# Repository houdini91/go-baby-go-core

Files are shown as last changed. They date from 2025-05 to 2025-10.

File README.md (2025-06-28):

# GoBabyGo Core Build Kit

This repository contains the core set of open-source 3D-printed components developed for **GoBabyGo** — a volunteer-driven nonprofit dedicated to building adapted electric cars for children with disabilities.

🖨️ Printable model pages:
🔗 [Core Build Kit Models](https://www.printables.com/model/875079-adaptive-electric-car-core-kit-gobabygo-israel)
🔗 [Stabilized Adaptive Push Button Models](https://www.printables.com/model/993443-stabilized-adaptive-switch-go-baby-go-il/files)

📘 Learn more in our blog post:
🔗 [Core Build Kit Overview](https://medium.com/@mikeystrauss/adapting-cars-for-children-with-disabilities-the-gobabygo-core-build-kit-08175c2a7b7c)

Maintainers:
* Mikey Strauss - GoBabyGo Israel - `mdstrauss91@gmail.com`
* Christopher Auger-Dominguez - Center for Initiatives in Jewish Education  
* Barbara Sehgal - Center for Initiatives in Jewish Education  

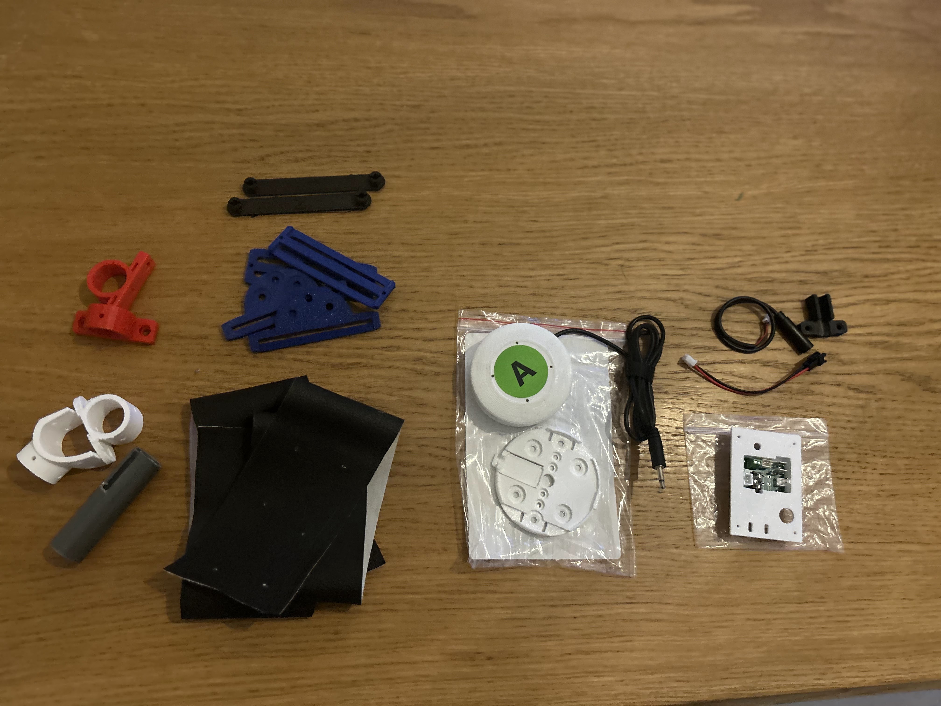
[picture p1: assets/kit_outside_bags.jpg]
Kit View

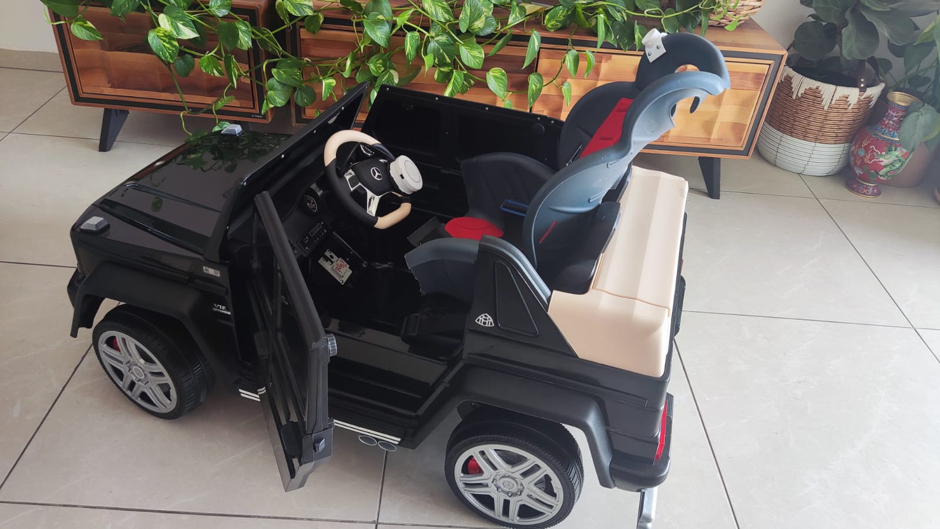
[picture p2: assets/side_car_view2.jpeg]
Car View


### Empowering Mobility Through Open, Accessible Design

At **GoBabyGo**, we believe every child deserves the freedom to move, explore, and experience independence. The **Core Build Kit** is our open-source effort to share the core components and lessons from years of building customized electric cars for children with disabilities.

This kit reflects over a decade of iterative learning, hands-on problem-solving, and feedback from hundreds of families and builders. Our mission is to make adaptive ride-on vehicles simpler, more consistent, and easier for other GoBabyGo chapters, makers, and caregivers to replicate and customize.

> 💡 The kit is built for collaboration. Whether you're improving it for your local chapter or adapting it to new use cases, we welcome your ideas and contributions.

---

### What's Inside the Kit?

#### 🔘 **Push Button Adaptation**

We replace foot pedals with accessible hand- or head-activated push buttons. The kit includes:

* A no-solder generic **pedal-to-jack adapter**
* Modular **push button mounts** for off-the-shelf (e.g., Logitech Adaptive Kit) and custom buttons
* Stable, flexible **mounting connectors** for various control schemes
* Mods and Extentions models for different use cases.

<!-- ![Pedal Jack Adaptor](assets/pedal_jack_adaptor.jpeg)
![Assembly Top](assets/pedal_jack_assembled_top.jpeg)
![Assembly buttom](assets/pedal_jack_assembled_buttom.jpeg)
![Pedal Jack Adaptor 3D](assets/pedal_jack_pcb_front_v1.png)
 -->

|  |  |
| --- | --- |
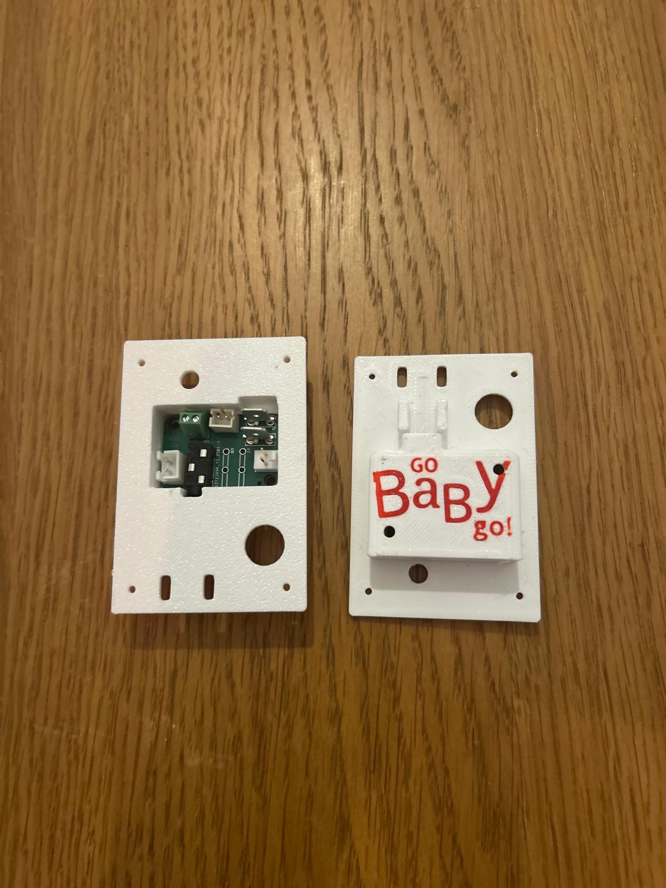
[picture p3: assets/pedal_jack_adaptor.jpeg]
Pedal Jack Adaptor
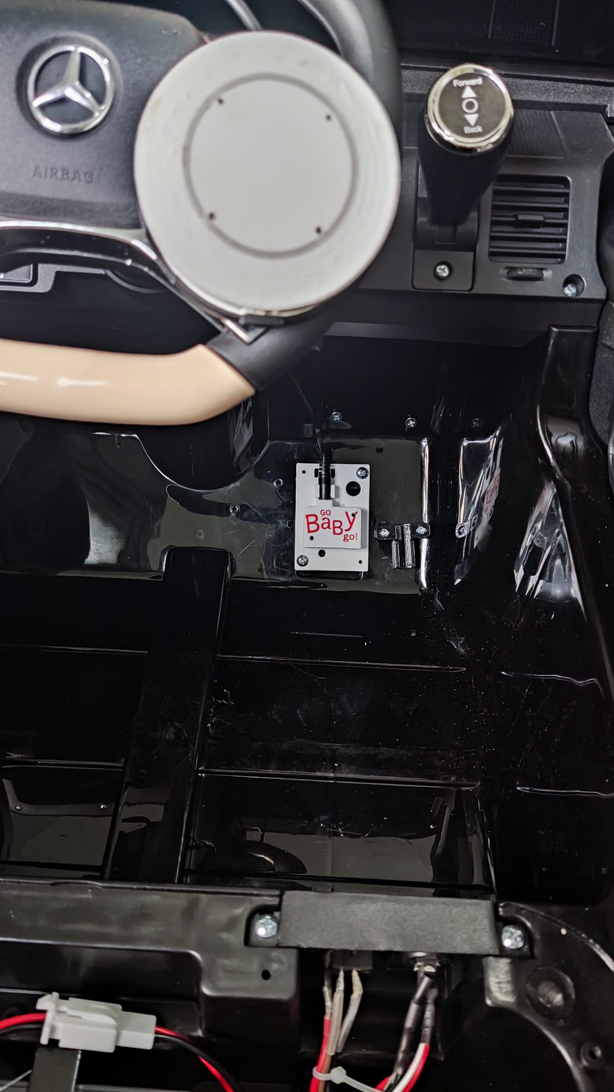
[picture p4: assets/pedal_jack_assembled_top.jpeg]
Assembly Top
| |  |
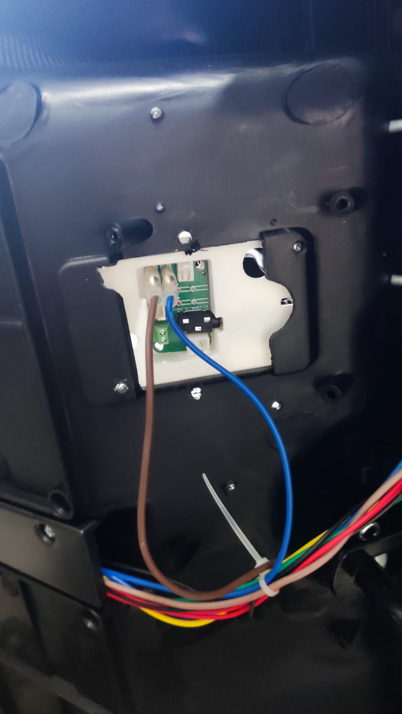
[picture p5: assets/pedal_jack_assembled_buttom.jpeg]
Assembly buttom
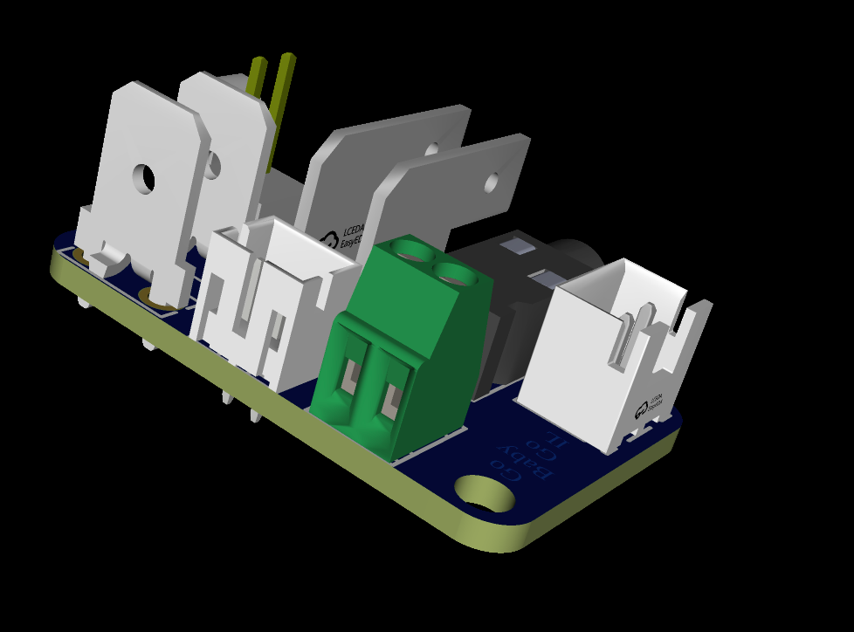
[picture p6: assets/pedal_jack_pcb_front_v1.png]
Pedal Jack Adaptor 3D
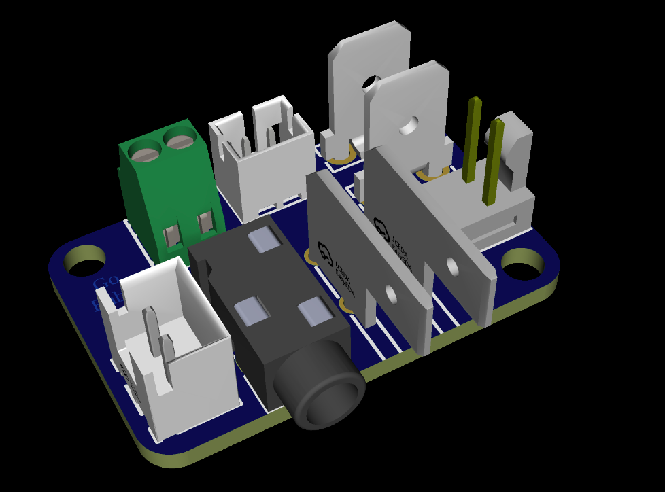
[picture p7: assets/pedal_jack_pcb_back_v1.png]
Pedal Jack Adaptor 3D
| | <br/> |

#### 🪑 **Seating Customization**

Standard seat belts rarely meet the needs of children with disabilities. Our approach:

* Wide, adjustable belts with printed mounts and tri-glide adjusters
* Low-profile mounts for use with adaptive bike seats and close-fitting car frames

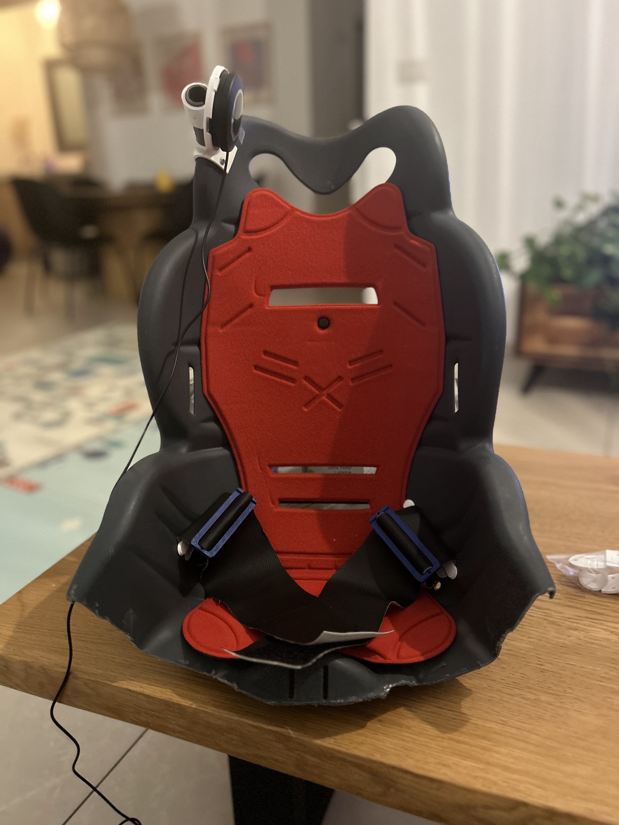
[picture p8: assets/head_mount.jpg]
Seat with head mount


#### 🧩 **Modular PVC Mounts**

* Headrests
* Lap boards
* External support structures

> Currently supporting 20mm PVC parts for building lightweight but sturdy.

### 🧠 Stabilized Adaptive Push Button (v1 – Prototype)

A robust, customizable switch (65mm) designed for adaptive electric cars, toys, and gaming environments. It offers enhanced stability, tactile feedback, and compatibility with common low-profile mechanical keyboard switches.

#### Key Features:

* **X/Y Stabilization** — Reduces wobble, improves actuation consistency
* **Swappable Springs** — Adjustable actuation force for different users
* **Snap-In Mounting** — Supports common low-profile switches (Gateron, Kailh)
* **Child-Friendly** — Durable with engaging tactile response
* **Logitech Gaming Kit Compatible** — Includes mounts for Logitech large buttons
* **JellyBean-Style Cap** — Transforms switch into a classic accessible form

> 📄 For detailed [information](./docs/stabilized_round.md) and 3D model files of the stabilized push button.

---

### Materials and Printing Recommendations

All printed parts are designed with accessibility and ease-of-use in mind. We recommend:

* **PETG** filament for safety and durability
* 0.35 mm layer height for most parts, 0.2 mm for fine details.
* Mounts designed for M3 screws or zip-tie options

---

### Why This Kit?

Crafted by the Israeli chapter of GoBabyGo —  Over the course of building \~800 adapted vehicles, we realized the value of **consistency**, **modularity**, and **collaboration**. The Core Build Kit simplifies complex adaptations without sacrificing the flexibility needed for each unique child. Our long-term vision is to see this kit evolve as a community tool—shared, improved, and loved by chapters and makers worldwide.

---

### Start Collaborating

Learn more about **GoBabyGo Core build kit** and our ongoing projects:

Submit issues, ideas, or improvements via this GitHub repo.
Join our informal WhatsApp group for builders and volunteers — request access via Facebook or LinkedIn.

🌐 [Website](https://www.gobabygo.org.il/english-1)
📘 [Facebook](https://www.facebook.com/gobabygoil/)
💼 [LinkedIn](https://www.linkedin.com/in/mikey-strauss-a4312999/)

> Need help building or printing parts? Reach out — we have parts in stock and are happy to support new builders.

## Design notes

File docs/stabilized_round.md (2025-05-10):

# Stabilized Adaptive Push Button

**Version 1 – PoC**
**Work in Progress**

### Overview

This adaptive push button is designed as a robust, modular interface for children’s ride-on vehicles, toys, and gaming systems. Its **stabilized mechanical design**, **snap-in support for low-profile keyboard switches**, and **customizable tactile feedback** make it ideal for a wide range of adaptive uses — from driving to gaming.

---

Top View
Internal View

### 🔧 Key Features

* **X/Y Stabilization:** Reinforced structure minimizes lateral wobble, ensuring consistent and reliable activation.
* **Swappable Springs:** Ships with multiple springs to customize actuation force (light to firm press).
* **Snap-In Compatibility:** Designed to fit low-profile mechanical switches like Gateron and Kailh Choc (Coch-style).
* **Child-Friendly Form Factor:** Intuitive for kids, with satisfying tactile feedback and strong durability.
* **Modular Design:** Snap-fit assembly supports quick maintenance and upgrades.
* **PVC Mounting:** Attaches to standard 20mm PVC (horizontal and vertical) for integration into adaptive cars and rigs.
* **JellyBean Button Cap:** Converts the unit into a familiar, accessible form for increased usability.
* **Logitech Adaptive Kit Support:** Includes optional mounts for Logitech’s Large Button from the Adaptive Gaming Kit.

---

### 🎮 Adaptive Gaming Compatibility

Thanks to its stability, clicky mechanical feedback, and 3.5mm mono jack output, this push button functions as a reliable **Coch switch replacement** for gaming use — especially with adaptive controllers such as:

* **Xbox Adaptive Controller (XAC)**
* **PlayStation with third-party adaptive interfaces**
* **PC-based accessibility setups**

This makes it an affordable, tactile, and child-friendly option for both **mobility and gaming accessibility**.

---

### 🛠 Suggested Components

* **Low-Profile Mechanical Switches:**

  * [Gateron KS-33 Low Profile 2.0 Switches – Official Store](https://www.gateron.co/products/gateron-low-profile-mechanical-switch-set)
  * Kailh Choc Low Profile switches (commonly available via keyboard modding suppliers)

* **Stabilizers:**

  * [YMDK Cherry PCB Stabilizers 3U / 40mm – Amazon](https://www.amazon.com/Original-Stabilizers-Satellite-Mechanical-Keyboard/dp/B07K8FZMV6?th=1)

* **Springs:**

  * 15x4mm compression springs (targeting 30–80g range — tuning and sourcing in progress)

* **Output:**

  * Standard **3.5mm mono jack**, compatible with most assistive switch interfaces

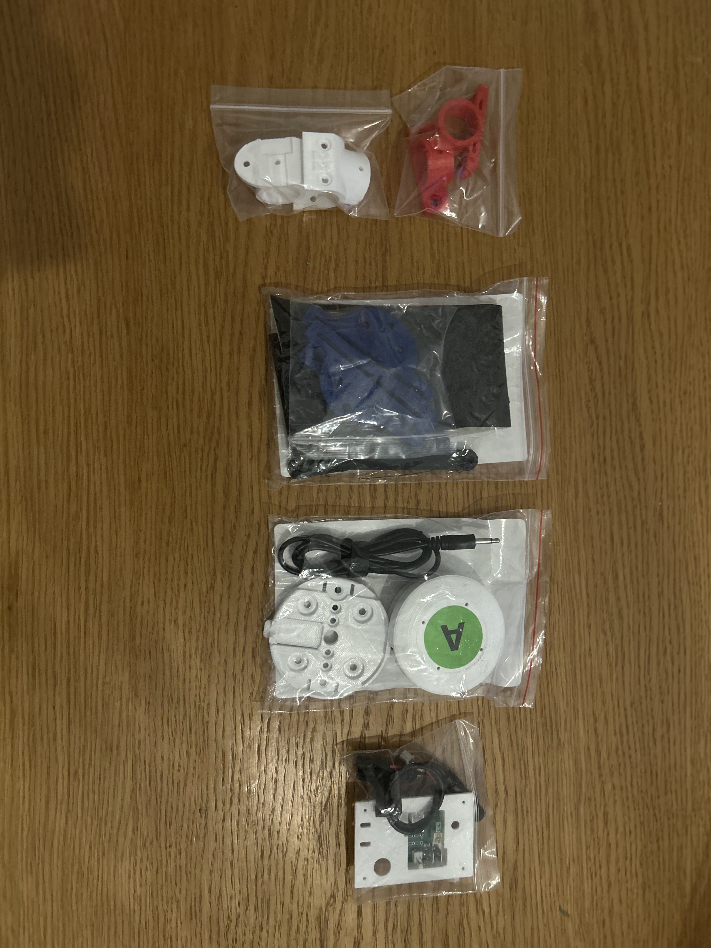
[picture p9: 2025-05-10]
assets/kit_in_bags2.jpg

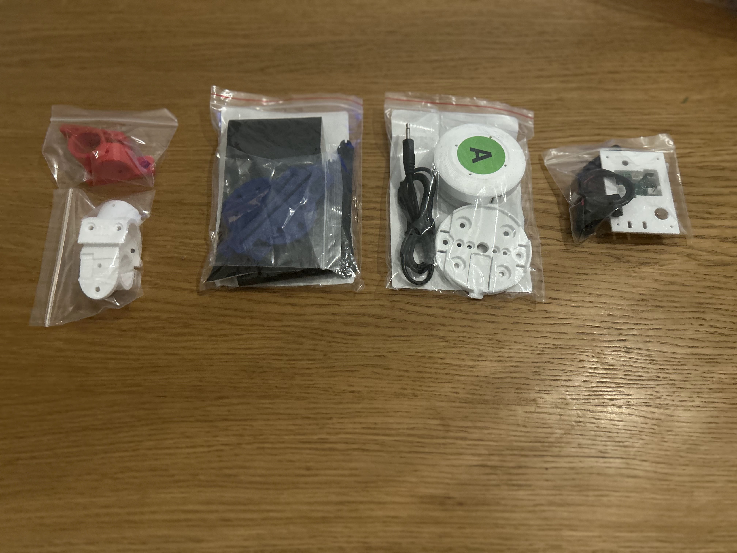
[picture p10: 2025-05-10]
assets/kit_in_bags.jpg

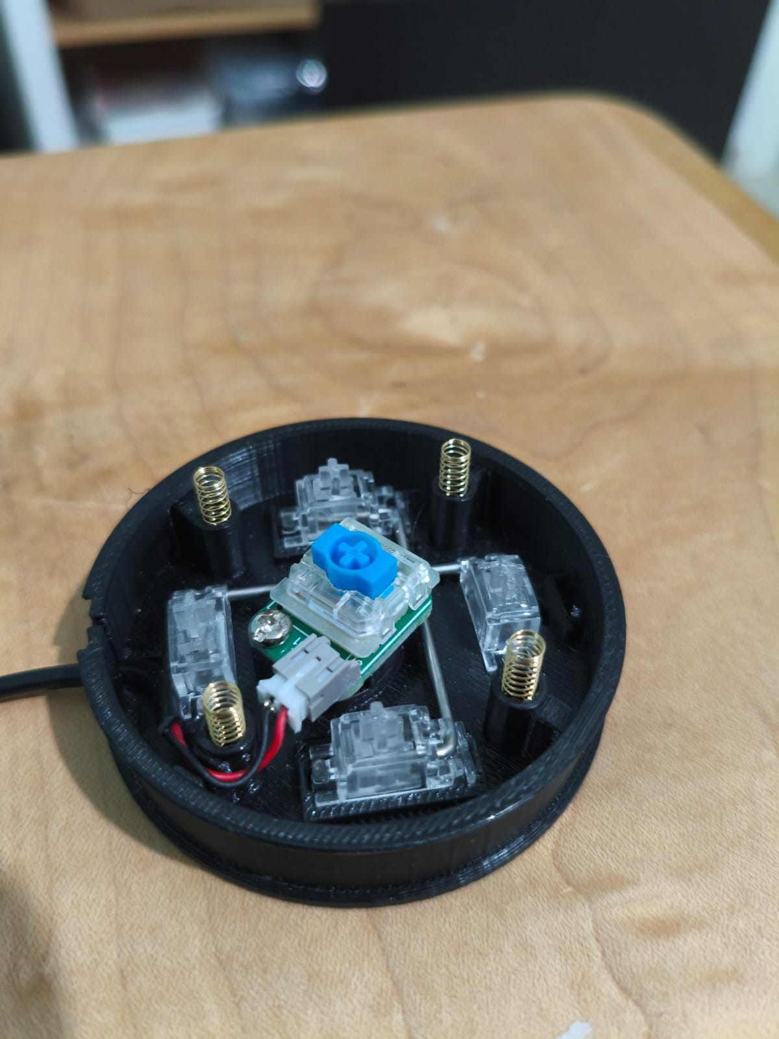
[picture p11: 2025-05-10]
assets/stabilized_button_internal_view.jpeg

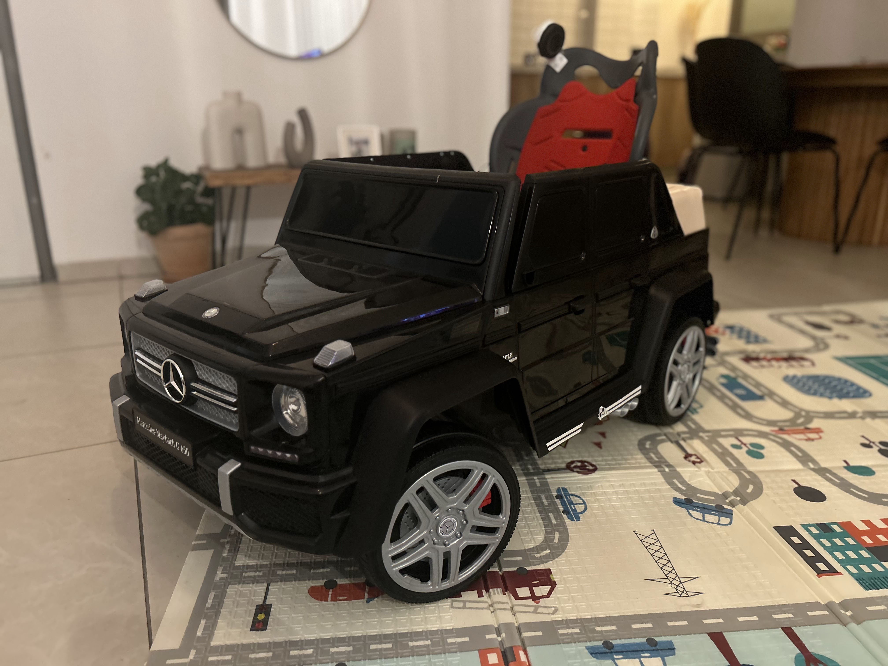
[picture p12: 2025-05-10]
assets/side_car_view.jpg

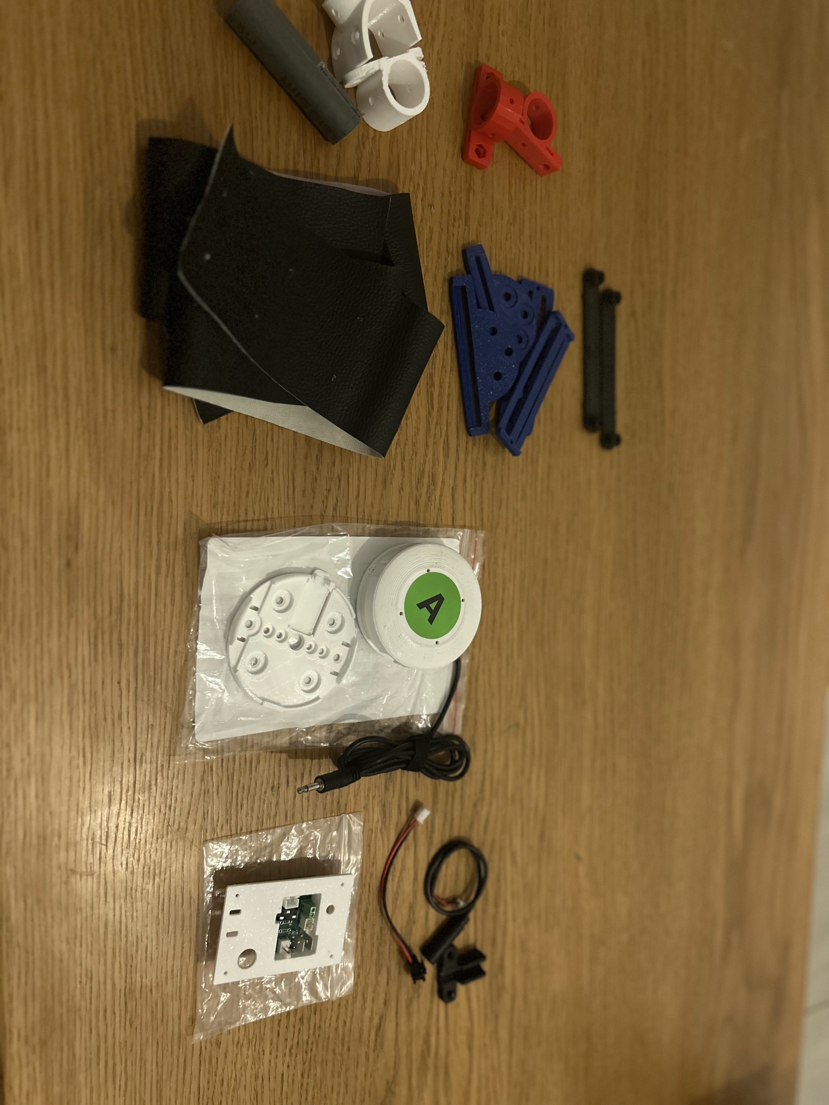
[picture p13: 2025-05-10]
assets/kit_outside_bags2.jpg

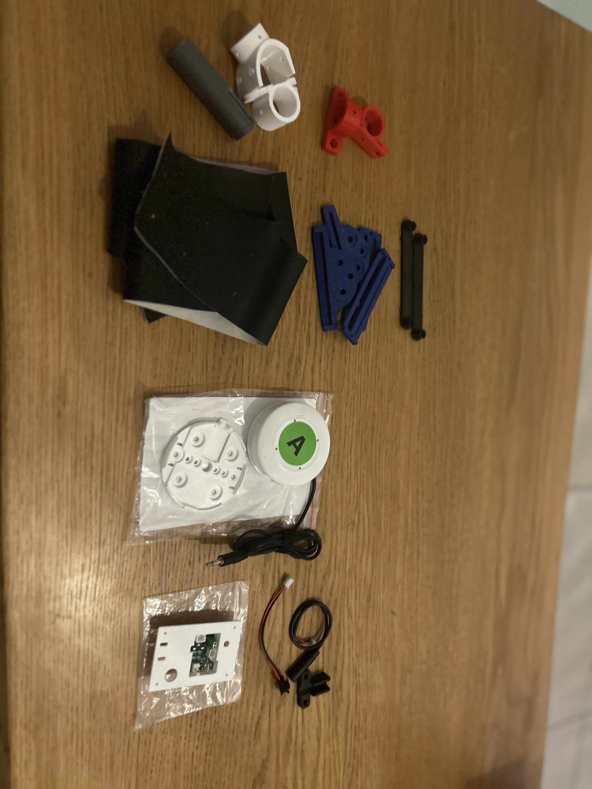
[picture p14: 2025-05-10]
assets/kit_outside_bags3.jpg

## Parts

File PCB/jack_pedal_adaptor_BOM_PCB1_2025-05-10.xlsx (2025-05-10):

No. | Quantity | Comment | Designator | Footprint | Value | Manufacturer Part | Manufacturer | Supplier Part | Supplier
1 | 1 | PJ-3200 | CN2 | AUDIO-TH_PJ-3200 |  | PJ-3200 | XKB Connectivity(中国星坤) | C2689690 | LCSC
2 | 1 | B2B-XH-A(LF)(SN) | CN3 | CONN-TH_B2B-XH-A-LF-SN |  | B2B-XH-A(LF)(SN) | JST | C158012 | LCSC
3 | 1 | 22112022 | CN4 | CONN-TH_22112022 |  | 22112022 | MOLEX | C505162 | LCSC
4 | 2 | 63849-1 | J1,J2 | CONN-TH_63849-1 |  | 63849-1 | TE Connectivity(泰科电子) | C86469 | LCSC
5 | 1 | JS20T-S02PHA-00 | U1 | CONN-TH_2P-P2.00_JS20T-S02PHA-00 |  | JS20T-S02PHA-00 | JS(钜硕电子) | C7499292 | LCSC
6 | 1 | KF128-2.54-2P | U6 | CONN-TH_P2.54_KF128-2.54-2P |  | KF128-2.54-2P | KEFA(科发) | C474920 | LCSC
7 | 2 | G480-10-1W | U7,U8 | CONN-TH_G480-10-1W |  | G480-10-1W | SAMZO(三佐) | C39833013 | LCSC

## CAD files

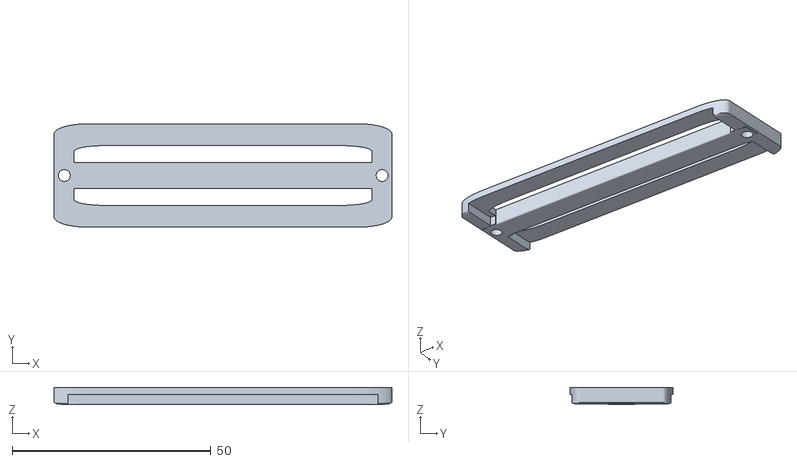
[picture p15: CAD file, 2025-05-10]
models/belt/tri-glide-8cm.stl
85.0 x 26.0 x 4.30

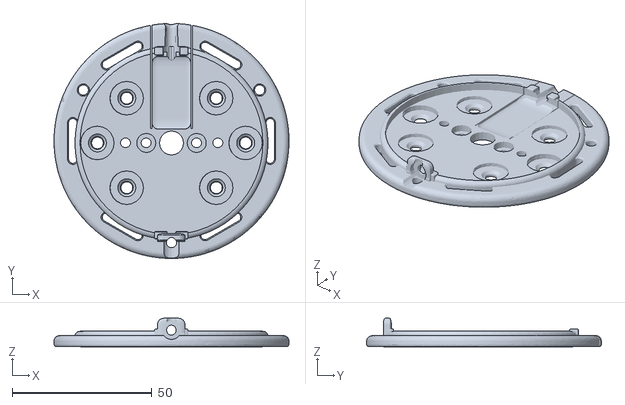
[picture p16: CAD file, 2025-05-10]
models/buttons/stabilized_round/large_switch_mount_jelly_bean.stl
84.0 x 84.0 x 10.2

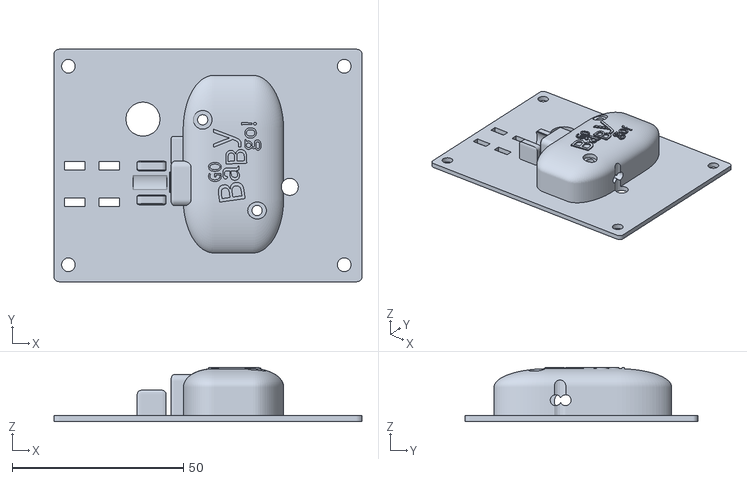
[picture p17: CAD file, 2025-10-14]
models/core/pedal_to_jack_adaptor_case.stl
90.0 x 68.0 x 15.9

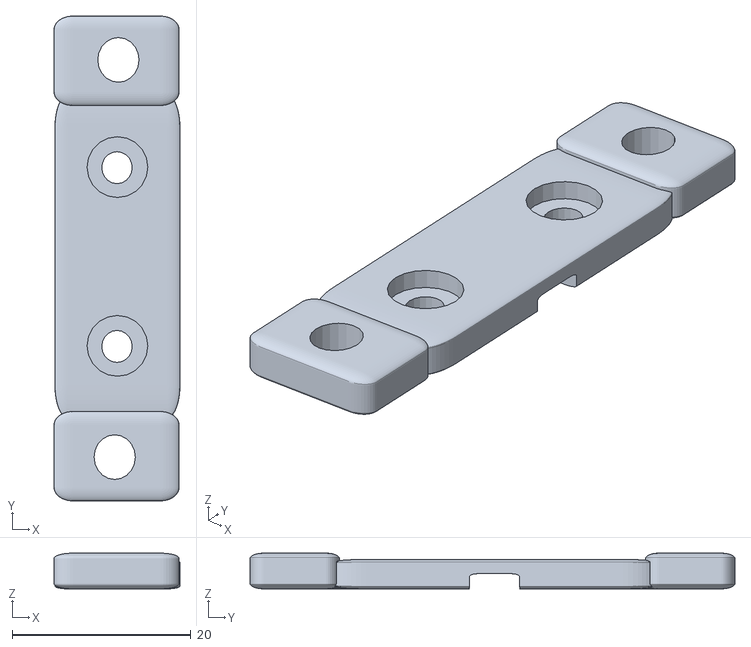
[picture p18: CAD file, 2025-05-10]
models/mounts/logitech_small_button_mount.stl
14.1 x 54.2 x 4.00

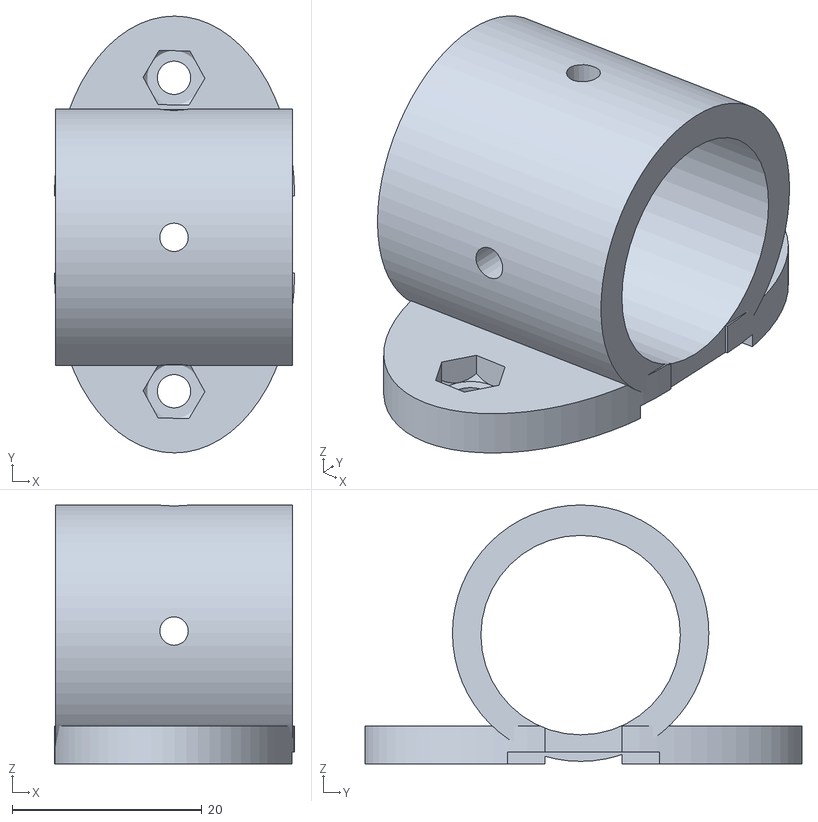
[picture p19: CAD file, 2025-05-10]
models/pvc/pvc_20mm_vertical_connector.stl
25.3 x 46.0 x 27.3

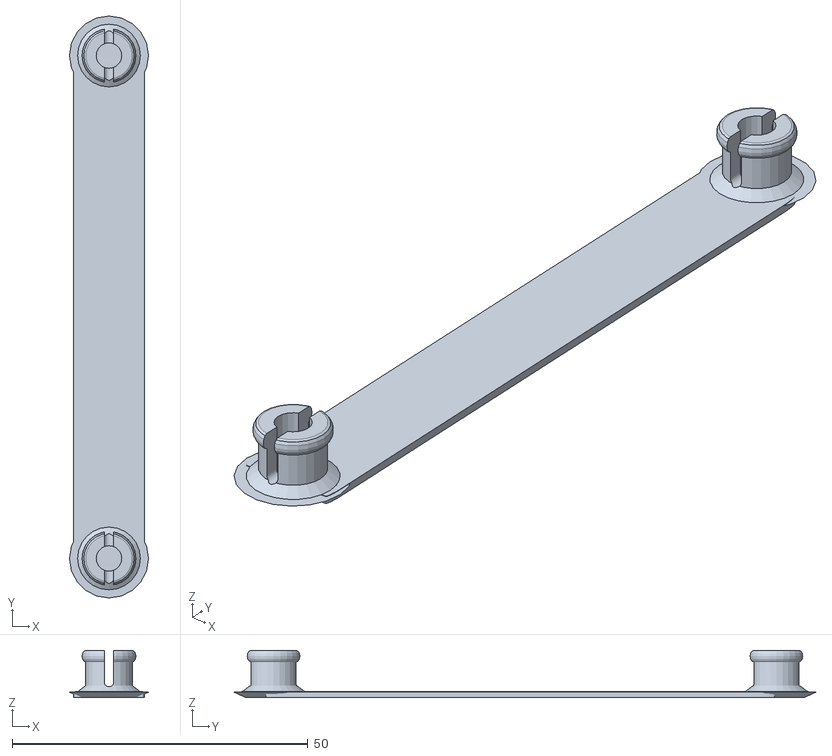
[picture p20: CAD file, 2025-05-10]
models/belt/belt_low_profile_mount_snap_in.stl
13.4 x 98.4 x 8.00

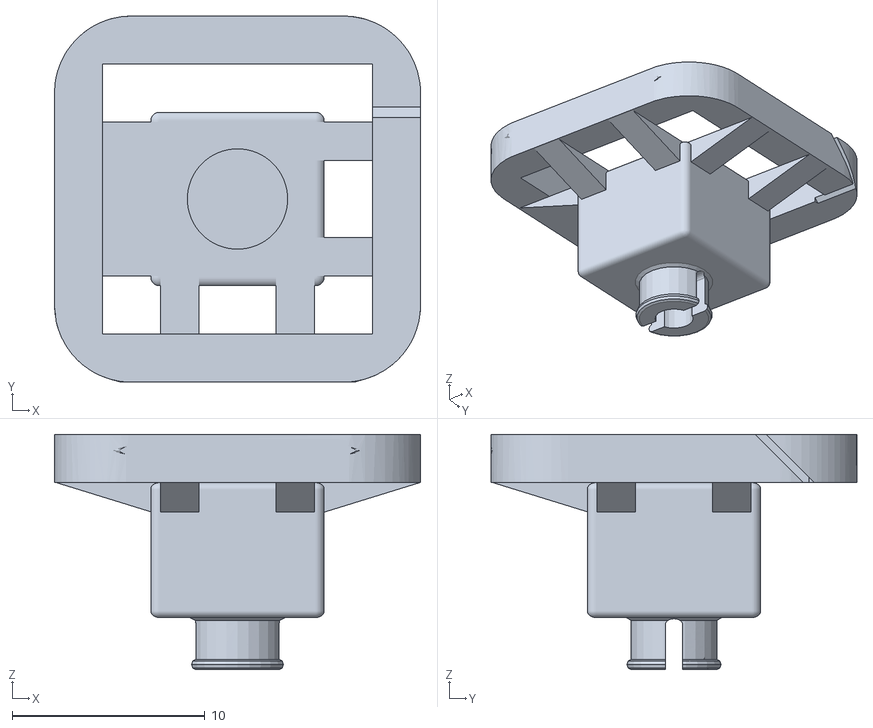
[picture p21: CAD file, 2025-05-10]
models/buttons/stabilized_round/low_profile_microswitch_mount.stl
19.0 x 19.0 x 12.2

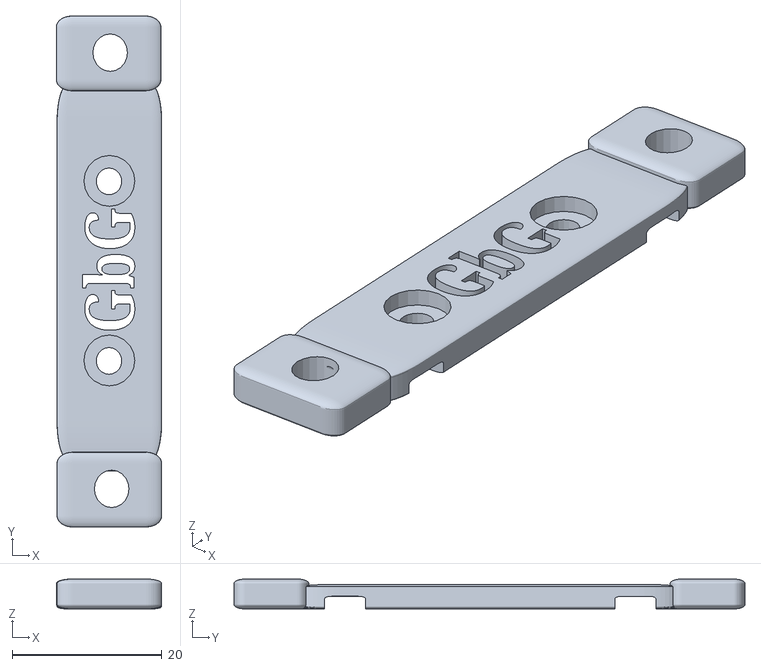
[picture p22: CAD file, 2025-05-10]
models/mounts/logitech_light_touch_button_mount.stl
14.1 x 68.3 x 4.00

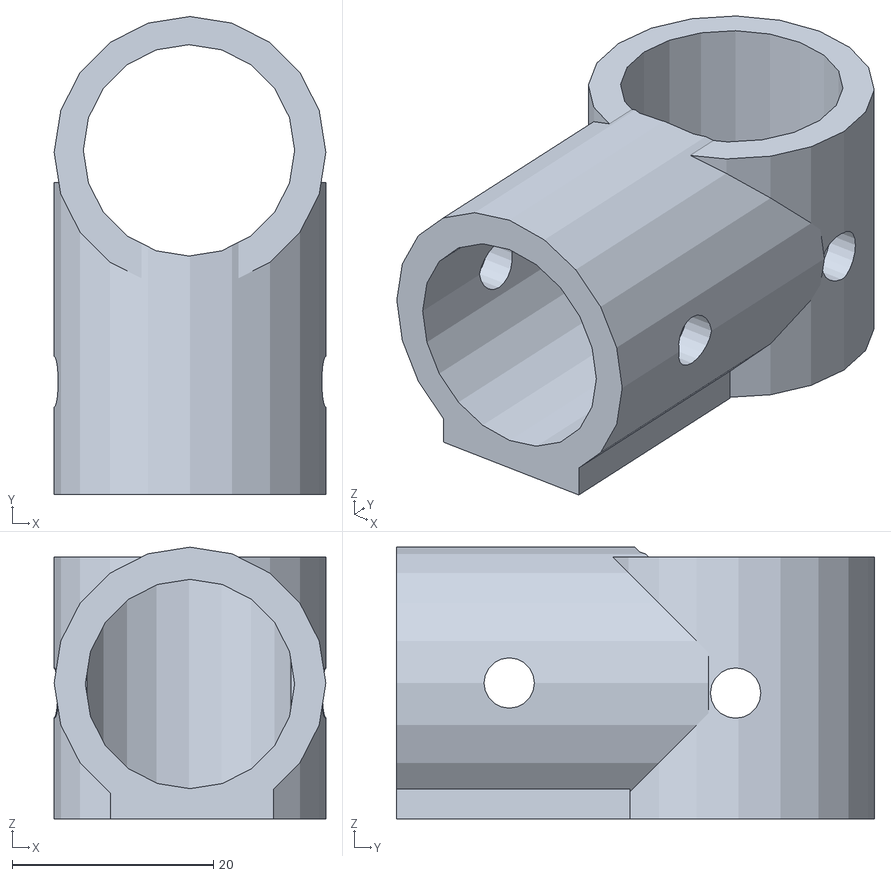
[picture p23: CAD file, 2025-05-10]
models/pvc/pvc_hinge_20mm.stl
27.0 x 47.5 x 27.0

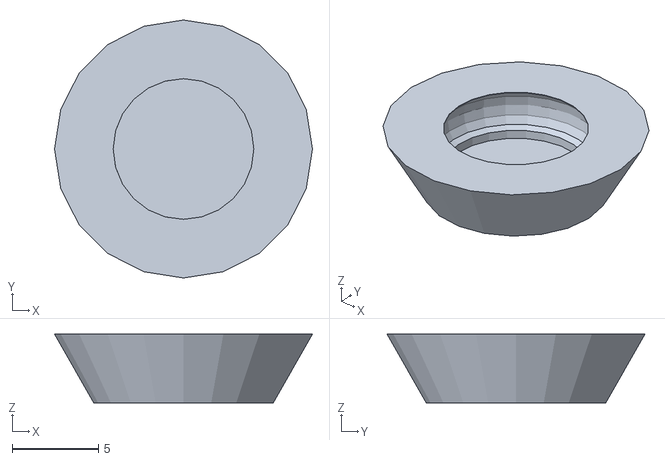
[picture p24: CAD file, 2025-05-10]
models/belt/belt_low_profile_mount_cap.stl
15.0 x 15.0 x 4.00

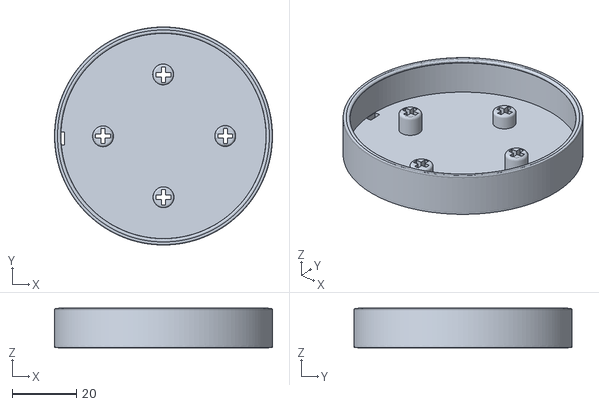
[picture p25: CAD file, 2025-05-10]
models/buttons/stabilized_round/large_switch_cap_buttom.stl
67.8 x 67.8 x 12.3

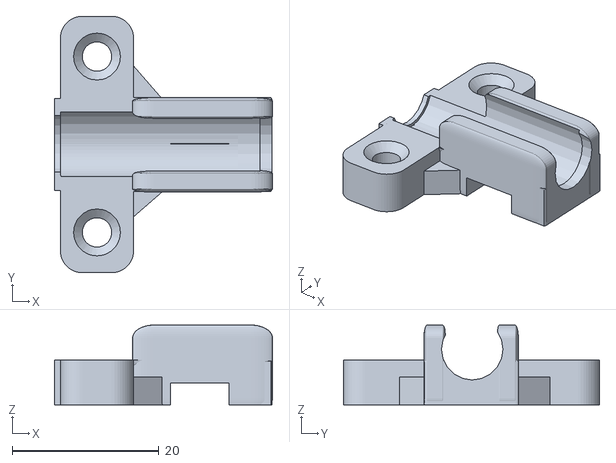
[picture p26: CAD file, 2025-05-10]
models/mounts/jack_plug_mount.stl
29.8 x 35.0 x 10.9

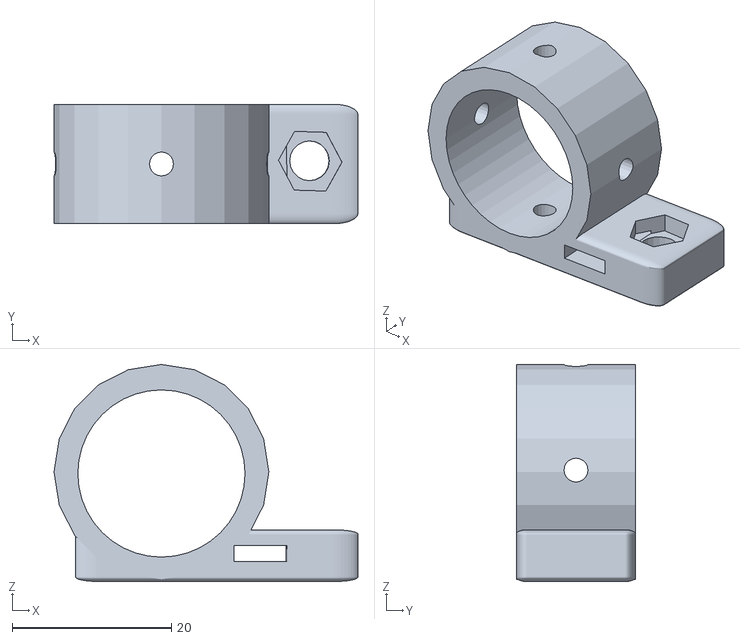
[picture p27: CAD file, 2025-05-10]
models/pvc/pvc_hindges_1_legged_20mm.stl
38.2 x 15.0 x 27.3

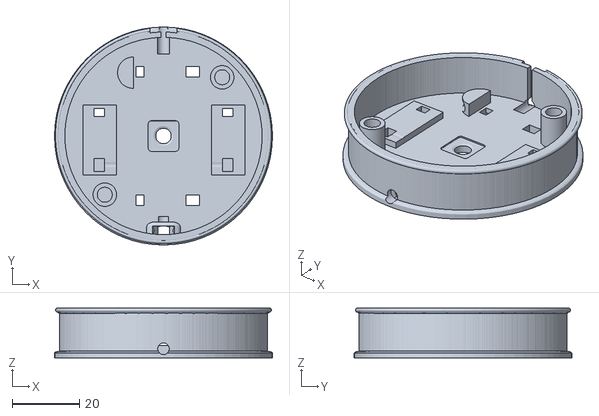
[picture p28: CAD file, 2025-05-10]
models/buttons/stabilized_round/large_switch_base.stl
65.0 x 65.0 x 14.9

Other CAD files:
models/pvc/pvc_holder_2_legged_20mm.stl
models/buttons/stabilized_round/large_switch_cap_top.stl
models/pvc/pvc_hinge_brace_20mm.stl
models/buttons/stabilized_round/large_switch_mount.stl
models/belt/belt-screw-mount-8cm.stl
models/buttons/stabilized_round/pvc_20mm_horizontal_connector.stl
models/buttons/stabilized_round/pvc_20mm_vertical_connector.stl
models/buttons/stabilized_round/pvc_head_mount_17_degrees.stl
models/buttons/stabilized_round/pvc_head_mount_22_degrees.stl
models/mounts/logitech_large_button_mount_old.stl

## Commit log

2025-05-10 Initial version
    [belt-screw-mount-8cm.stl, belt_low_profile_mount_cap.stl, belt_low_profile_mount_snap_in.stl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]
2025-06-08 Larger base, larger Jack entry
    [pedal_to_jack_adaptor_case.stl]
2025-10-14 new Jack case
    [pedal_to_jack_adaptor_case.stl]
2026-11-12 Add pommel v0.7 (pre-first-print) for GbG_chair_forth
    Medial knee support for the GbG_chair_forth seat insert, ages 2-5.
    STATUS: PRE-FIRST-PRINT. Nothing has been printed, load-tested or
    fitted on a child yet; all fits and strength figures are estimates.
    - models/seating/pommel: Onshape FeatureScript sources (pommel with
    6 sizes, print set, rod fit test, built-in snap-off supports; chair
    recess + teardrop rod holes), print guide, and a sign-off checklist.
    - docs/pommel: body-measurement reference sketch (small vs big child),
    the v0.7b design sketch, expert-panel review, background research.
    - README: link under Seating, marked work in progress.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
2026-11-12 Pommel v0.7: first-prototype STLs, wider neck base, slicer supports
    Still PRE-FIRST-PRINT.
    - STLs for the first prototype: rod fit-test bar and S23A for a chair
    without the recess. Real P1S/PETG slices: 12.9 g / 28 min and
    113.7 g / 3 h 40 min (with slicer supports).
    - Long sizes: the neck widens to 56 mm below seat level (under the
    thighs, within the pad width). About 8 mm of plastic beside the rod
    channels instead of 2.8 mm.
    - Built-in snap-off support is now optional and off by default; use
    slicer tree supports on the hidden saddle underside.
    - Print guide: corrected strength section, neck infill modifier, real
    slice numbers. Chair reference updated to Main V11, which has the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
2026-11-12 Pommel v0.7.1: remove the neck base, keep the neck clean
    The wider neck base added in v0.7 gave only ~10-15% strength, didn't
    flow into the hook and pad, and left an edge a calf could catch. It's
    removed. Strength now comes from printing the long sizes' neck nearly
    solid (slicer modifier), as the print guide says. The short sizes and
    the committed STLs (fit test, S23A) are unaffected. Onshape version
    v0.7.1 pre-first-print.
2026-11-12 Pommel v0.7.2: fuller neck on the long sizes
    The long sizes' neck looked pinched: 36 mm wide, dipping to 1 mm above
    the seat. It's now 46 mm wide with its top 10 mm above the seat, level
    with the hook lip and with no dip, so it flows from the hook into the
    pad. It sits in the wedge under and between the thighs.
    - About 2x stronger (hand estimates): SF ~6 at an adult 300 N press on
    the K45 pad tip, ~12 for a 200 N sideways knee push.
    - K45A now also gets the full 10 mm leg-edge rounding (was 6.5 mm).
    - The short sizes and the committed STLs (fit test, S23A) are
    unchanged. Onshape version v0.7.2 pre-first-print.
    Still PRE-FIRST-PRINT.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
